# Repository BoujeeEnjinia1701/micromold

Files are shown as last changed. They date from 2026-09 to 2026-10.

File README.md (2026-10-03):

# MicroMold

     

**Area:** Advanced Manufacturing · **TRL:** 3 of 9 (proof of concept on paper) · **Value-engineering target:** USD 520 (estimated cost USD 590) · **Difficulty:** 3 of 5

A desktop injection molding press for recycled plastic: a lever or screw press with a heated barrel and interchangeable aluminum molds, turning shredded waste plastic into small useful parts.

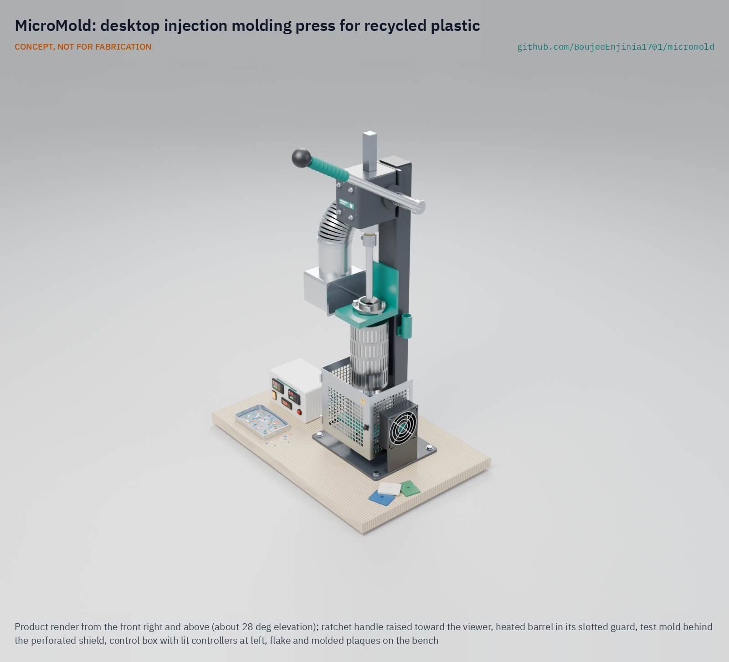
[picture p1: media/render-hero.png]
MicroMold: desktop injection molding press for recycled plastic, product render


[Exploded render](media/render-exploded.png) · [Interactive 3D model](media/viewer.html) · [Concept blueprint (PDF)](media/concept-blueprint.pdf) · [General arrangement (PDF)](cad/drawings/MMD-DWG-001.pdf) · [Sizing calculations](docs/04-calcs/01-sizing.md) · [Prototype build plan](docs/05-build-plan.md) · [Design decisions](docs/06-design-decisions.md) · [Review note](docs/REVIEW.md)

## Concept rationale

Molding turns sorted flake into finished parts, which sell for far more than flake sold by weight, and it lets a community make the small parts it would otherwise import. MicroMold uses the simplest injection process that still gives useful pressure: a heated barrel, a hand-driven plunger and a bolted aluminum mold. The drive is the rack and pinion of a 1 t arbor press on a taller column, turned by a ratchet handle, which gives a long stroke and 22.5:1 advantage from one bought tool (the brief allows a lever or screw drive; Amish chose this one on 2026-09-25).

It is open and garage-buildable because the value is in local making. Only the barrel and the molds need a lathe or mill, which most towns have in a machine shop, and a new mold costs tens of dollars in aluminum and machining rather than thousands for steel tooling. Open drawings let groups repair the press, share molds and adapt it, as the Precious Plastic community has done for its own machines.

## Burning platform

Only 9 % of the world's plastic waste is successfully recycled, while most is landfilled, incinerated or leaks into the environment ([OECD, 2022](https://www.oecd.org/en/about/news/press-releases/2022/02/plastic-pollution-is-growing-relentlessly-as-waste-management-and-recycling-fall-short.html); [*Global Plastics Outlook*](https://www.oecd.org/en/publications/global-plastics-outlook_de747aef-en.html)). Municipal solid waste reached 2.56 billion tonnes in 2022 and is projected to reach 3.86 billion tonnes by 2050, while collection covers only 31 % of waste in sub-Saharan Africa and 67 % in South Asia ([World Bank, *What a Waste 3.0*](https://www.worldbank.org/en/publication/what-a-waste)).

Recycling groups need products that pay for collection, and exporting scrap is getting harder: since 1 January 2021 the Basel Convention plastic waste amendments have required prior informed consent for most mixed or contaminated plastic waste shipments ([Basel Convention](https://www.basel.int/implementation/plasticwaste/amendments/overview/tabid/8426/default.aspx)). Adding value locally, by molding parts, is one of the few routes left for small operators.

## Where it could be used

### By industry

| Industry | Use |
| --- | --- |
| Community recycling and social enterprise | Turn sorted HDPE and PP flake into hooks, clips, knobs and tiles for local sale |
| Education and vocational training | Teach polymer processing, mold design and the circular economy with a press students can take apart |
| Repair and maintenance | Short runs of discontinued knobs, spacers, bushings and clips |
| Product design and prototyping | Low-cost aluminum bridge tooling to test a part in real thermoplastic before paying for steel molds |
| Agriculture and construction | Non-structural items such as cable clips, tile spacers, plant labels and hose guides (not food contact) |

### By country or region

| Country or region | Why it matters there |
| --- | --- |
| Kenya | Single-use plastic carrier and flat bags have been banned since 2017 ([NEMA](https://www.nema.go.ke/index.php?option=com_content&view=article&id=241)); durable recycled products are a natural outlet for collected HDPE and PP |
| Sub-Saharan Africa | Collection covers only 31 % of waste ([World Bank](https://www.worldbank.org/en/publication/what-a-waste)); products that pay for collection make it viable |
| South Asia (India, Bangladesh) | Collection reaches 67 % ([World Bank](https://www.worldbank.org/en/publication/what-a-waste)); as collection grows, sorted flake needs local outlets that add value |
| Brazil | The National Solid Waste Policy (Law 12,305 of 2010) directs public cleaning services to prioritize cooperatives of low-income waste pickers and allows federal support for their equipment ([Planalto, Lei 12.305/2010](https://www.planalto.gov.br/ccivil_03/_ato2007-2010/2010/lei/l12305.htm), arts. 36 and 42); a press is the kind of equipment that lets a cooperative sell parts rather than flake |
| United States | Plastics recycling was 8.7 % in 2018 ([US EPA](https://www.epa.gov/facts-and-figures-about-materials-waste-and-recycling/plastics-material-specific-data)); makerspaces and schools can use it for local recycling programs |
| Europe (Netherlands and wider EU) | Precious Plastic workspaces already run open lever presses ([Precious Plastic Academy](https://onearmy.github.io/academy/build/injection)); a bench press with higher pressure widens what they can mold |

## What sparked the idea

The starting point was the machine widely credited as the first injection molder. In 1872 the brothers John Wesley and Isaiah Smith Hyatt of Albany, New York, patented an apparatus in which a plunger pressed celluloid stock through a heated cylinder and out of a discharge nozzle, with a two-part mold held shut by a clamp to receive it ([US Patent 133,229, 1872](https://patents.google.com/patent/US133229A/en)). Every part of MicroMold is already in that patent: a plunger, a heated vertical barrel, a nozzle and a clamped split mold. Industry later moved to reciprocating screws and machines of many tonnes, but the plunger layout remains the simplest way to mold small parts, and it asks for no motor, gearbox or screw. The gap between that 150-year-old principle and the open lever press of Precious Plastic, which reaches about 45 bar from a floor-standing frame ([Precious Plastic Academy](https://onearmy.github.io/academy/build/injection)), is the space MicroMold aims at: a bench press with about twice the pressure for recycled flake.

## Problem

Community recycling produces shredded plastic with few local uses, and small-batch molding of parts is out of reach without an injection press. Only about 9 % of plastic waste is recycled worldwide, and groups that do collect and shred plastic often sell flake by weight for little return. Design with, not for: requirements must come from co-design sessions with recycling groups through a local partner.

## Concept

A bench-top, hand-operated plunger injection press. The rack-and-pinion head of a 1 t arbor press, on a taller steel column and turned by a ratchet handle through a torque-limiting socket, drives a 22 mm plunger down a vertical barrel heated by two 300 W band heaters and a 100 W nozzle heater, each zone under PID control. Melt fills a bolted two-plate aluminum mold held against a 4 mm nozzle by a screw lift table inside a perforated shield, where a small fan cools the mold; a load cell under the ram shows the injection force, and a side hood with a duct fan draws fumes from the funnel. The TRL 3 calculations give up to 34 g of HDPE per shot at 8.9 MPa (89 bar) with 250 N on the handle in about four ratchet pulls, a 12.3 min warm-up, about 11 parts per hour and 753 W from a single-phase socket. Value-engineering target: USD 520. Estimated cost of the constructable design: USD 590 (USD 70 over the target) for the press, and USD 684 with one mold; the press weighs about 39.8 kg against its 40 kg target (see the [sizing calculations](docs/04-calcs/01-sizing.md) and the [review note](docs/REVIEW.md)).

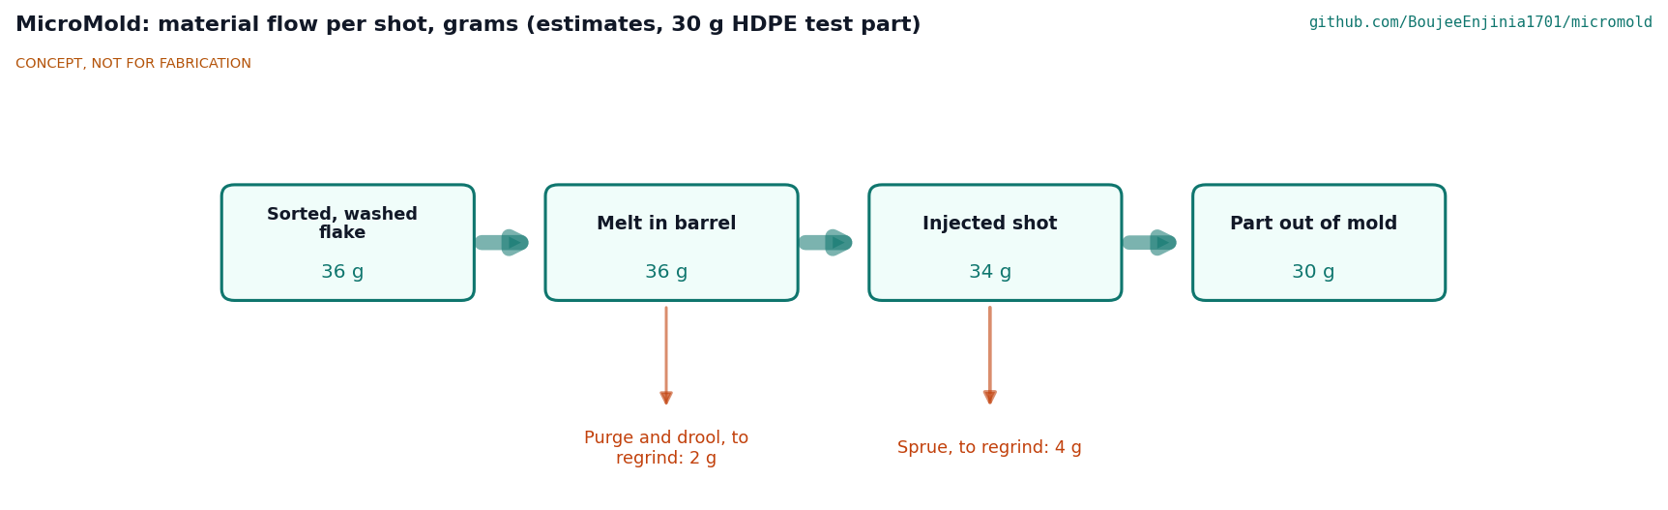
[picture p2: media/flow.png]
Material flow


Full design precis: [docs/02-concept.md](docs/02-concept.md)

## Key components

- Heated steel barrel (22 mm bore) with two 300 W band heaters, and a 4 mm nozzle with a 100 W heater
- Rack-and-pinion drive head from a 1 t arbor press on a steel column, with a 450 mm ratchet handle
- 22 mm plunger with a load cell, on a glass-epoxy thermal spacer, for force and pressure indication
- Two-plate aluminum mold set on a lift table raised by a handwheel nut on a Tr20 screw
- Insulation jacket and perforated guard; perforated nozzle zone shield
- Side fume hood with a 100 mm inline duct fan
- 120 mm mold cooling fan on the base plate
- Control box with two PID controllers, SSRs, fused inlet and independent thermal cut-out

The priced bill of materials is in [bom/bom.csv](bom/bom.csv); the parametric model is [cad/src/model.py](cad/src/model.py), with STEP and STL exports in `cad/step/` and `cad/stl/`.

## Building the prototype

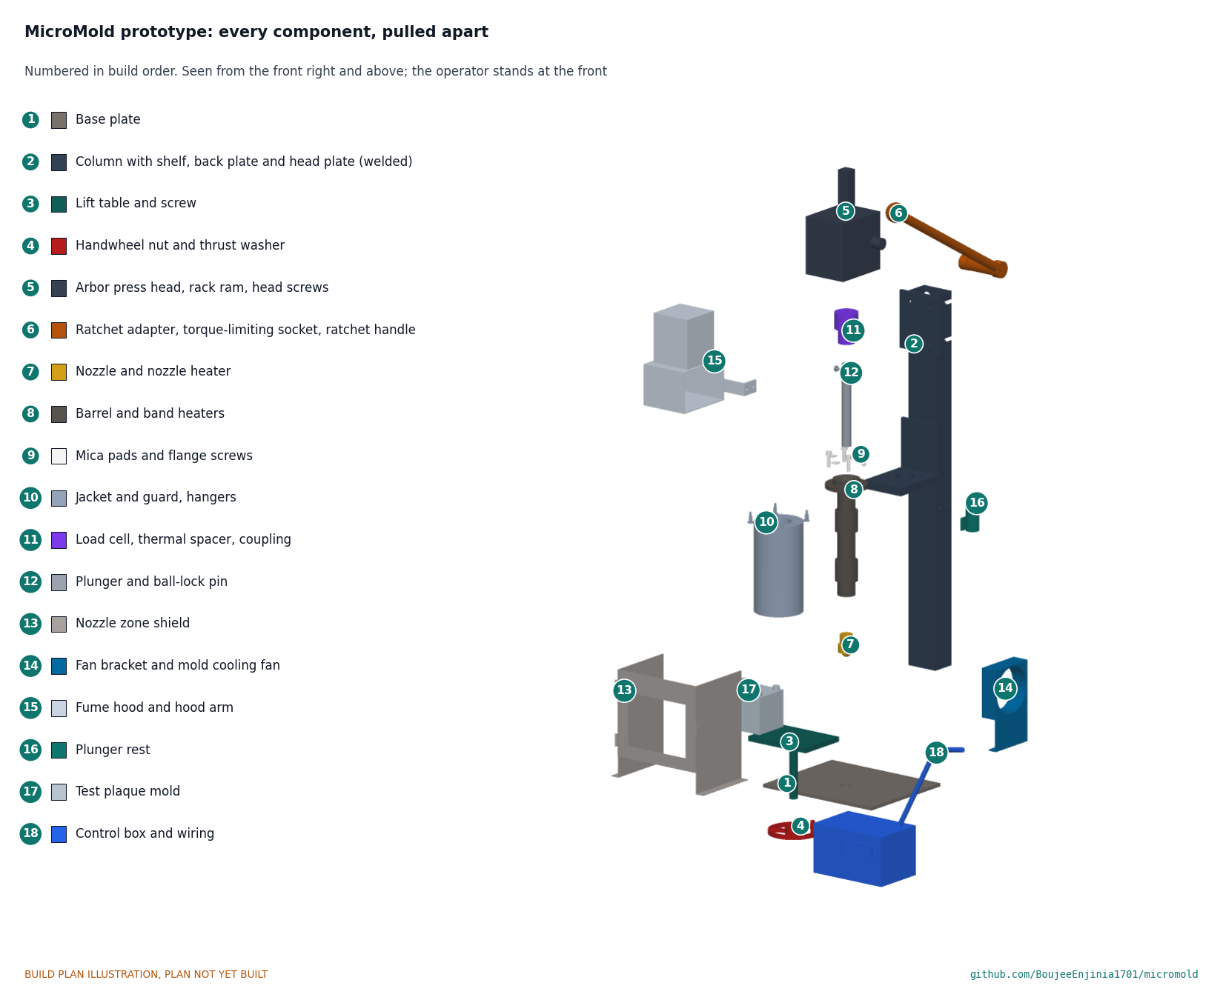
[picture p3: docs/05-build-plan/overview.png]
MicroMold prototype: every component pulled apart and numbered in build order


The [prototype build plan](docs/05-build-plan.md) (MMD-BLD-001) shows, in pictures, how to make each of the seventeen components and put them together in fourteen steps; nothing has been built yet. The frame is a steel column welded to a base plate with a shelf and a head plate, the barrel, nozzle and mold come from a local machine shop, the arbor press head is cut from its frame and bolted on, and the shield, fan bracket and hood are cut and folded from sheet. Writing the plan made the design buildable: the head and barrel fixings, the screw lift, the split jacket, the plunger coupling and the mold fastening were redesigned and fixings added (MMD-DDR-003, open for Amish's review). Every picture is drawn from the model, which checks that each part touches what it should, clears what it should not and can be put in place in the order given. Decisions still open are in the [design decisions register](docs/06-design-decisions.md).

## Safety

> **Safety:** Hot barrel, nozzle and molten plastic at up to 260 °C: use guards, heat-resistant gloves, long sleeves and eye protection, and keep faces off the injection axis. Close the nozzle zone shield before injecting. Process only HDPE, PP, LDPE and PS; never heat PVC or unknown plastics, and run the hood fan whenever the heaters are on, or work outdoors. Mains-voltage heaters: earth all metal parts, use a fused inlet and an RCD or GFCI supply, and have mains wiring done or checked by a qualified electrician to local electrical code. Keep hands clear of the rack, and release the ratchet pawl only with the handle in hand. See the safety section of the [design precis](docs/02-concept.md).

## Repository layout

| Folder | Contents |
| --- | --- |
| `docs/` | Problem, concept, requirements, calculations and design decisions |
| `cad/src/` | build123d Python source, the source of truth for all geometry |
| `cad/step/`, `cad/stl/` | Exported models for FreeCAD, other CAD tools and printing |
| `cad/drawings/` | 2D sketches and dimensioned drawings |
| `bom/` | Bill of materials |
| `electronics/` | KiCad schematics and PCB layouts |
| `firmware/` | Microcontroller code |
| `media/` | Renders, perspectives and photos |
| `build-log/` | Dated prototyping notes |

## Documentation

Controlled documents follow the portfolio [documentation standard](.kit/STANDARDS.md). Each carries a document ID (MMD-PRC-001 for the precis), a version and a revision history. Branded PDFs are built with `python .kit/render.py` and attached to GitHub Releases when a document is tagged, for example `MMD-PRC-001/v1.0`.

## Credits

Designed by Amish Chadha. See [CONTRIBUTORS.md](CONTRIBUTORS.md) for roles. To cite this design, use [CITATION.cff](CITATION.cff) (GitHub shows it as "Cite this repository").

AI assistance (Claude) was used to accelerate concept renders, prototype documentation and first-pass sizing calculations. Design direction and all decisions are Amish Chadha's, recorded in this repository's decision records (`docs/decisions/`).

## Licenses

- **Hardware** (CAD, drawings, BOM, electronics): [CERN-OHL-S v2](LICENSE)
- **Software** (firmware, scripts, notebooks): [MIT](LICENSE-SOFTWARE)

A project of the [Design Molecule](https://designmolecule.com) lab.

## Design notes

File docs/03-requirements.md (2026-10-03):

---
doc_id: MMD-REQ-001
title: MicroMold requirements
project: MicroMold
doc_type: Requirements
version: "0.8"
status: Draft
date: '2026-10-03'
author: Amish Chadha
license: CERN-OHL-S-2.0
revisions:
- version: "0.1"
  date: '2026-09-25'
  author: Amish Chadha
  change: Initial scaffold
- version: "0.2"
  date: '2026-09-25'
  author: Amish Chadha
  change: First measurable requirements for TRL 2, with status against first-order estimates
- version: "0.3"
  date: '2026-09-25'
  author: Amish Chadha
  change: TRL 3 status from MMD-CAL-001; R14 redefined to the press excluding molds and R13 to name the hood (MMD-DDR-001 D8, D9)
- version: "0.4"
  date: '2026-09-25'
  author: Amish Chadha
  change: Recommendations accepted by Amish (DDR-002)
- version: "0.5"
  date: '2026-09-26'
  author: Amish Chadha
  change: Budget approved by Amish
- version: "0.6"
  date: '2026-10-01'
  author: Amish Chadha
  change: Status from MMD-CAL-001 v0.4 for the constructable design (MMD-DDR-003); R14 measured against the value-engineering target
- version: "0.7"
  date: '2026-10-02'
  author: Amish Chadha
  change: Figures brought into line with MMD-CAL-001 v0.5 - R9 mass 39.8 kg, R14 press USD 590 (USD 70 over the target); no requirement status changed
- version: "0.8"
  date: '2026-10-03'
  author: Amish Chadha
  change: "R9 mass margin of 0.2 kg and the 180 N m socket setting accepted by Amish on 2026-10-03"
---

# MicroMold requirements

These are the requirements for the concept, checked by calculation at TRL 3 in MMD-CAL-001. Targets are proposals for review, not yet validated with users, and will be revised after co-design sessions (see MMD-PRB-001). "Met on paper" means met by calculation, and "met by design" means met by a stated feature; neither is demonstrated on hardware. Two targets changed in v0.3 under MMD-DDR-001: R14 covers the press without molds (D8), and R13 names the hood (D9). Three more changed in v0.4 under MMD-DDR-002, decided by Amish on 2026-09-25: R1 requires injection-grade flake, R9 allows 40 kg (was 35 kg) and R14 allows $500 (was $400). In v0.5 R14 allows $520, the budget Amish approved on 2026-09-26 to cover the priced BOM (MMD-DDR-002). In v0.6 that figure is read as a hypothetical value-engineering target, not a limit (Amish, 2026-10-01), and status is from MMD-CAL-001 v0.4, for the constructable design of MMD-DDR-003.

The **reference part** used throughout is a 30 g HDPE test plaque, 64 x 50 x 6 mm, molded from washed, dried flake of 3 to 8 mm.

Table 1. Requirements.

| ID | Requirement | Target | Status (MMD-CAL-001) | Verification (TRL 3 or later) |
| --- | --- | --- | --- | --- |
| R1 | Process the safe recycled thermoplastics | HDPE, PP, LDPE and PS flake of 3 to 8 mm from injection-molded items (caps, crates, buckets); bottle-grade HDPE and PVC excluded by procedure and labeling | Met by design (bottle grade would need about 24 MPa, CAL E6) | Design review; material trials later |
| R2 | Shot size | 30 g or more of HDPE per injection | **At risk:** 34.2 g ideal, about 25 g if the fresh charge is not tamped | Swept-volume calculation; later weighed shots |
| R3 | Injection pressure | 8 MPa (80 bar) or more at the melt with 250 N or less on the handle | Met on paper: 8.9 MPa at 0.60 drive efficiency (12.4 MPa at 0.84); fill needs about 4.8 MPa | Force and friction calculation; later load cell reading |
| R4 | Temperature control | Barrel and nozzle zones each settable from 150 to 260 °C, held within ±5 °C at the thermocouple; independent cut-out above 280 °C | Met by design, unverified | Controller and heater datasheets; later logging |
| R5 | Warm-up | Cold start to 220 °C in 15 min or less | Met on paper: 12.3 min with two 300 W bands | Heat capacity calculation; later timed start |
| R6 | Throughput | 8 or more reference parts per hour with one mold | Met on paper: 11.6 per hour with the mold cooling fan, mold about 47 °C (soak limited) | Cycle-time estimate; later timed trials |
| R7 | Mold envelope | Molds up to 150 x 120 mm footprint and 40 to 120 mm stack height; 40 cm² or more projected area at full pressure | Met on paper: 45 cm²; stacks of 30 to 120 mm fit | Clamp force calculation; model |
| R8 | Low-cost tooling | A two-plate aluminum mold for the reference part machinable on a manual mill or small CNC for $100 or less | Met on paper: $94 (indicative) | Quotation from a local shop |
| R9 | Bench size and mass | Press footprint 350 x 300 mm or less, top of handle 1.1 m or less above the bench, mass 40 kg or less without the control box | **At risk on mass:** 39.8 kg with an assumed 8 kg press head (0.2 kg margin accepted by Amish, 2026-10-03; 180 N m socket setting accepted the same day); 320 x 260 mm and 1,094 mm met | Model and mass estimate |
| R10 | Power supply | Single-phase 230 V or 120 V, 1 kW or less, 10 A or less at 120 V | Met on paper: 753 W, 6.3 A at 120 V | Heater and fan ratings |
| R11 | Touch-safe outer surfaces | Guard and jacket 60 °C or less at 220 °C set point and 25 °C ambient; nozzle and mold zone guarded | Met on paper: skin 48 °C; nozzle zone shield added | Thermal calculation |
| R12 | Electrical safety | Earthed frame, fused inlet, double-pole switch, RCD or GFCI supply, heaters and wiring rated for 250 °C at the barrel | Met by design, unverified | Design review against IEC 60204-1 principles |
| R13 | Fume control | A side hood with a duct fan at the funnel, and operation only under it or outdoors; set points above 260 °C blocked in the controller | Met on paper: about 124 m³/h | Hood calculation; design review |
| R14 | Affordable | Parts for the press, excluding molds (tooling, see R8), at or under the $520 value-engineering target (a hypothetical control target) | **Over the value-engineering target: $590, USD 70 over** ($684 with one mold) | Priced BOM (`bom/bom.csv`) |
| R15 | Garage-buildable | Everything except the barrel and the mold built with hand tools, a drill press and optional welding | Met by design: the barrel with its nozzle and the molds come from a local machine shop; the plunger is only cross-drilled | Build sequence review |
| R16 | Repeatable parts | Part mass within ±3 % over 10 consecutive shots | Not verifiable at TRL 3 | Later bench trials (TRL 4, not in the current phase) |

## Assumptions

- HDPE melt density about 0.75 g/cm³ at 200 to 220 °C; solid density about 0.95 g/cm³ (typical handbook values, estimates). The other property values are in MMD-CAL-001, Table 1.
- Arbor press drive: pinion pitch radius about 20 mm, 450 mm ratchet handle, design efficiency 0.60 (0.84 calculated), to be checked on the chosen press.
- Processing temperatures follow published melt ranges: HDPE 190 to 230 °C, PP 200 to 240 °C, LDPE 220 to 245 °C, PS 180 to 260 °C ([RJC Mold](https://rjcmold.com/guides/plastic-melting-point-chart)).
- Four M10 class 8.8 cap screws in thread inserts, preloaded to about 20 kN each, clamp the mold plates, with a factor of 2 against melt pressure opening the parting plane.

## Requirements not met or at risk

- **R14 cost:** value-engineering target: USD 520. Estimated cost of the constructable design: USD 590 (USD 70 over the target) for the press, with molds counted as tooling; USD 684 with the first mold. The parts added to make the design buildable account for USD 37 (MMD-DDR-003) and the plunger rest and torque-limiting socket for USD 46 (decisions of 2026-10-02); cost drivers and savings are in MMD-DEC-001.
- **R9 mass:** 39.8 kg against 40 kg, with an assumed 8 kg arbor press head; the margin depends on the real press.
- **R2 shot size:** met only if each top-up of flake is tamped with the press while loading.
- **R16** cannot be assessed until hardware exists (TRL 4, on hold).

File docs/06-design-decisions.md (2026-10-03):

---
doc_id: MMD-DEC-001
title: MicroMold design decisions register
project: MicroMold
doc_type: Design decisions register
version: "0.4"
status: Draft
date: '2026-10-03'
author: Amish Chadha
license: CERN-OHL-S-2.0
revisions:
  - version: "0.1"
    date: '2026-10-01'
    author: Amish Chadha
    change: Register opened with the build plan; budget treated as a value-engineering target
  - version: "0.2"
    date: '2026-10-02'
    author: Amish Chadha
    change: Amish approved the recommendations for open items 1 to 7 on 2026-10-02 (MMD-DDR-003 accepted with P1 confirmed against the bought press, lift-out loading with a plunger rest, bench hole, torque-limiting socket, Precious Plastic workspace near Irving as first candidate, first product mold, appearance model); moved to decisions made
  - version: "0.3"
    date: '2026-10-02'
    author: Amish Chadha
    change: Value engineering updated for the torque-limiting socket and plunger rest (press USD 590, USD 70 over the target)
  - version: "0.4"
    date: '2026-10-03'
    author: Amish Chadha
    change: "Amish accepted the 180 N m socket setting and the 0.2 kg R9 mass margin on 2026-10-03; row added to decisions made"
---

# MicroMold design decisions register

Every design decision still to be made, and every decision made, in one place. Each decision is argued in full in its decision record under `docs/decisions/`; this register is the index Amish works from. The build plan (`docs/05-build-plan.md`) describes the design as it stands and does not list open decisions.

## Open decisions

None. All open decisions were decided on 2026-10-02.

## To confirm when parts are bought

| # | What to confirm | Why it matters | Source |
| --- | --- | --- | --- |
| 1 | The arbor press: a 28 mm ram 255 mm or longer with 150 mm of engaged travel; a head that can be cut from its frame with a flat back face and enough metal for four M10 holes 20 deep; the head's mass (8 kg assumed) | Sets the stroke, the head fixing and R9's mass margin (1.0 kg) | MMD-DDR-003, P1; MMD-CAL-001 [K1] |
| 2 | The press's lever hub: its outside diameter and bore, to take the welded square drive | The ratchet adapter is made from it | MMD-DDR-003, P13 |
| 3 | The load cell is about 56 mm across, has a top M12 stud and a base flange with three M5 through holes (46 mm circle assumed) | The spacer's tapped holes are drilled to match it | MMD-DDR-003, P6 |
| 4 | The handwheel's hub takes a Tr20 x 4 nut (about 36 mm across) | The handwheel nut is made from it | MMD-DDR-003, P7 |
| 5 | The mold cooling fan's corner holes are on a 105 mm square | The fan bracket's holes | MMD-DDR-003, P10 |
| 6 | The nozzle heater band fits a 24 mm body and is no more than 18 mm wide | The nozzle body length | MMD-DDR-003, P4 |
| 7 | The bench top's thickness and the clear space under it (60 mm or more below the hole) | The lift screw drops through it | MMD-DDR-003, P7 |

## Value engineering

Value-engineering target: USD 520 (a hypothetical control target, not a limit). Estimated cost of the constructable design: USD 590 (USD 70 over the target) for the press; USD 684 with the test mold, which is tooling outside the target (USD 94, R8). Main cost drivers and savings worth trying:

- The largest lines are the arbor press head with column tube and ratchet (USD 110), the control box (USD 55), the fume hood and duct fan (USD 48), the barrel (USD 45), the load cell and display (USD 35) and the lift table, screw and handwheel (USD 30).
- Making the design constructable added USD 37: the construction parts of line 19 (USD 30: head mounting plate and screws, plunger coupling and ball-lock pin, ratchet adapter, hood arm and rivnuts), the bracket's back plate and cap screws (USD 4) and the shield's hinges and latch (USD 3). The mold rose USD 4 for screws, inserts and dowels.
- The decisions of 2026-10-02 added USD 46: the torque-limiting socket (line 21, USD 40, an estimate at the midpoint of a USD 30 to 50 retail band) and the plunger rest (line 20, USD 6, an estimate by parts).
- Savings worth trying: a used arbor press (often under half the new price); counting the duct fan and duct (USD 48) as workshop extraction shared with other machines, as the molds are counted as tooling, which would bring the press to USD 542 (that removes cost from scope rather than saving it, so it does not compare like with like with the target); buying the two PID controllers and relays as a pre-wired dual-zone controller; and a ball-lock pin replaced by a plain clevis pin and R-clip (about USD 4 less).

## Decisions made

| Date | Decision | Decided by | Record |
| --- | --- | --- | --- |
| 2026-09-25 | TRL 2 review items D1 to D10: rack-and-pinion drive from a 1 t arbor press on a taller column, vertical barrel with the mold below, plunger injection, two PID zones, bolted two-plate molds on a screw lift table, 10 kN load cell, test plaque first, molds as tooling, side hood with duct fan, a partner that already shreds HDPE or PP | Amish: "i accept all your recommendations, go with them across all repos." | MMD-DDR-001, MMD-DDR-002 |
| 2026-09-25 | N1 to N5: budget USD 500 for the press, 40 kg mass target, two 300 W barrel bands, a mold cooling fan, injection-grade flake only | Amish, same instruction | MMD-DDR-002 |
| 2026-09-26 | Budget USD 520 to cover the priced BOM (O3, option (a)) | Amish: "i approve all the budget items." | MMD-DDR-002 v0.2 |
| 2026-09-30 | Make the design physically buildable as the build plan is drawn; changes recorded as draft for review | Amish: "If you are realising that the design cannot be built as per concept - fix the design assumptions to match and be physically feasible as you draw the illustrations." | MMD-DDR-003 (its changes were accepted on 2026-10-02, below) |
| 2026-09-30 | Outstanding decisions are kept in this register, not in the build plan | Amish: "don't log outstanding decisions in this build plan - that is not the place for it." | This register |
| 2026-10-01 | `budget_usd` is a hypothetical value-engineering target, not a spending limit | Amish: "the budgets are a hypothethical control target to ensure we are thinking along a value engineering lens." | This register; MMD-REQ-001 R14 |
| 2026-10-02 | Design for construction accepted: the changes P1 to P15, with one condition: P1 (cutting the head from the arbor press casting and tapping four M10 holes in its back) is confirmed against the bought press before it is cut | Amish: "i approve your recommendations for all 555 open decisions." | MMD-DDR-003, Table 1 |
| 2026-10-02 | Loading: option (a), pull the ball-lock pin and lift the plunger out to load, then refit it to tamp and inject; a simple plunger rest is added on the column so the hot plunger is never laid on the bench | Amish: "i approve your recommendations for all 555 open decisions." | MMD-DDR-003, A1 |
| 2026-10-02 | Lift screw: option (a), a 25 mm hole through the bench for the lift screw is accepted | Amish: "i approve your recommendations for all 555 open decisions." | MMD-DDR-003, A2 |
| 2026-10-02 | Overload protection: option (b), a torque-limiting socket on the ratchet adapter, set so the ram cannot exceed the press rating, and checked against the load cell at TRL 4 | Amish: "i approve your recommendations for all 555 open decisions." | MMD-DDR-003, A3; `docs/REVIEW.md`, TRL 3 safety concerns |
| 2026-10-02 | First co-design partner: a community plastic recycling workspace that already shreds HDPE or PP; first candidate to approach a Precious Plastic workspace near Irving, Texas | Amish: "i approve your recommendations for all 555 open decisions." | MMD-DDR-001, O1 |
| 2026-10-02 | First product mold after the test plaque: a flat, single-cavity part of 25 g or less that fits the 120 x 90 mm mold plates, such as a coaster, tile or cable clip, chosen with the partner from what it can sell | Amish: "i approve your recommendations for all 555 open decisions." | MMD-DDR-001, O2 |
| 2026-10-02 | Appearance model: accept differences 1, 3, 5 and 6; update 2 and 4 to the constructable design (no guide rods; cap screws into inserts, no nuts), and add the screw lift, flange and fan bracket at the same time | Amish: "i approve your recommendations for all 555 open decisions." | `docs/REVIEW.md`, 2026-09-26, items 1 to 6 |
| 2026-10-03 | The 180 N m setting of the torque-limiting socket and the R9 mass margin of 0.2 kg (39.8 kg against 40 kg) accepted | Amish: "TIght Margins - i accept the margins" | MMD-REQ-001, R9; MMD-CAL-001; [REVIEW.md](REVIEW.md), session 2026-10-03 |

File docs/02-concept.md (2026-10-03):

---
doc_id: MMD-PRC-001
title: MicroMold design precis
project: MicroMold
doc_type: Design precis
version: "0.8"
status: Draft
date: '2026-10-02'
author: Amish Chadha
license: CERN-OHL-S-2.0
revisions:
- version: "0.1"
  date: '2026-09-25'
  author: Amish Chadha
  change: Initial scaffold
- version: "0.2"
  date: '2026-09-25'
  author: Amish Chadha
  change: Populate to TRL 2 (architecture, components, first-order numbers, design choices, safety, open questions, media)
- version: "0.3"
  date: '2026-09-25'
  author: Amish Chadha
  change: TRL 3 update from MMD-CAL-001 and MMD-DDR-001 (ratchet handle, 4 mm nozzle, load cell spacer, 20 mm bracket, nozzle zone shield, side fume hood, raised nozzle; numbers and design choices updated)
- version: "0.4"
  date: '2026-09-25'
  author: Amish Chadha
  change: Recommendations accepted by Amish (DDR-002)
- version: "0.5"
  date: '2026-09-26'
  author: Amish Chadha
  change: Budget approved by Amish ($520)
- version: "0.6"
  date: '2026-10-01'
  author: Amish Chadha
  change: Constructable design (MMD-DDR-003) and build plan (MMD-BLD-001); budget read as a value-engineering target
- version: "0.7"
  date: '2026-10-02'
  author: Amish Chadha
  change: 'Decisions of 2026-10-02 (MMD-DEC-001 v0.2): lift-out loading with a plunger rest, torque-limiting socket against overload, first product mold, first candidate partner'
- version: "0.8"
  date: '2026-10-02'
  author: Amish Chadha
  change: Figures brought into line with MMD-CAL-001 v0.5 - torque-limiting socket and plunger rest in Table 1 (items 19 to 21), overload 8.3 kN with the socket, mass 39.8 kg, press USD 590
---

# MicroMold design precis

## Summary

MicroMold is a bench-top, hand-operated plunger injection press for recycled HDPE, PP, LDPE and PS. The rack-and-pinion head of a 1 t arbor press, mounted on a taller steel column and turned by a 450 mm ratchet handle through a torque-limiting socket set to 180 N m, drives a 22 mm plunger down a vertical steel barrel heated by two 300 W band heaters. Melt leaves a heated 4 mm nozzle into a two-plate aluminum mold that a screw lift table holds against the nozzle, inside a perforated nozzle zone shield, where a small fan cools the mold, and a side hood with a duct fan draws fumes from the funnel. The TRL 3 calculations (MMD-CAL-001 v0.5) give a shot of up to 34.2 g at 8.9 MPa (89 bar) with 250 N on the handle, delivered in about four ratchet pulls; a warm-up of 12.3 min; and about 11.6 parts per hour from 753 W of single-phase power. Value-engineering target: USD 520. Estimated cost of the constructable design: USD 590 (USD 70 over the target) for the press, and USD 684 with one mold, which is tooling. It weighs about 39.8 kg against a 40 kg target. All figures are estimates. The design was made buildable on 2026-10-01 (MMD-DDR-003) and the prototype build plan is MMD-BLD-001 (`docs/05-build-plan.md`).

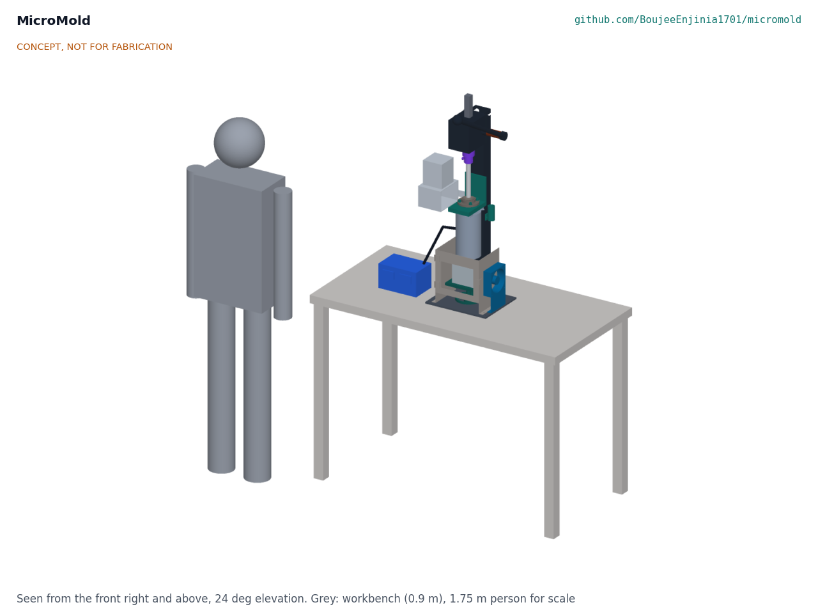
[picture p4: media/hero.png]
MicroMold on a workbench


*Figure 1. MicroMold on a 0.9 m workbench with a 1.75 m person for scale. Plunger raised for loading; test mold seated on the nozzle inside the shield. Generated from the parametric model `cad/src/model.py`.*

## How it works

1. **Heat.** Two PID controllers drive the barrel zone (two 300 W band heaters) and the nozzle zone (a 100 W band heater) to the set point for the resin, for example 210 °C for HDPE. An insulation jacket and a perforated guard keep the outer surface near 48 °C. The duct fan runs whenever the heaters are on. Feedstock is flake from injection-molded items such as caps, crates and buckets; bottle-grade HDPE is too stiff for a hand press.
2. **Load.** The operator pulls the ball-lock pin, lifts the plunger out and sets it on a plunger rest on the column, never on the bench (decided by Amish, 2026-10-02), pours washed, dried flake into the funnel, refits the plunger and tamps each of two or three top-ups down with the press itself, because loose flake has about a third to a half of the density of melt and an untamped charge wastes stroke (MMD-CAL-001, A4).
3. **Soak.** The fresh charge melts above the melt left from the last shot. The barrel holds 2.2 shots, so each charge soaks for about two cycles, about 12 min, against the 9.3 min a 22 mm column of tamped flake needs.
4. **Clamp.** The operator bolts the two mold plates together, sets the mold on the lift table, closes the shield's front and turns the handwheel nut, reached under the front, until the nozzle seats in the mold's spherical seat.
5. **Inject and hold.** The operator fills the mold in about four pulls of the ratchet handle, each moving the plunger about 31 mm, over about 10 s; the pawl holds the ram between pulls. The operator then holds pressure for about 30 s while the gate freezes. A load cell above the plunger shows its force, so the melt pressure (force divided by 380 mm² of plunger area) can be read and logged.
6. **Cool and eject.** With the mold cooling fan running, the plaque cools in the mold for about 1 min, then the mold is lowered, unbolted and opened. Sprue and purge go back to the regrind bin.

Material flow per shot

*Figure 2. Material flow per shot for the 30 g reference part. All values are estimates: about 2 g of purge and drool and 4 g of sprue return to regrind.*

## Main components

Table 1. Main components. Numbers match `bom/bom.csv` and Figure 4.

| # | Component | Choice | Notes |
| --- | --- | --- | --- |
| 1 | Base plate | 320 x 260 x 8 mm steel, bolted to the bench | Carries the column and the mold clamp; 8 mm from MMD-DDR-003 |
| 2 | Column and drive head | Rack-and-pinion head of a 1 t arbor press on an 80 x 60 x 3 mm steel tube column 0.9 m tall; 450 mm, 1/2 in drive ratchet handle on the pinion shaft | Ratchet added at TRL 3: one pull moves the plunger only about 31 mm |
| 3 | Rack ram | From the arbor press, 28 mm square, 255 mm or longer | 150 mm of travel with the rack still engaged; to confirm on the chosen press |
| 4 | Plunger load cell | 10 kN compression cell with HX711 amplifier and display, on a 10 mm G-11 glass-epoxy spacer | The spacer keeps the cell near 27 °C instead of about 94 °C |
| 5 | Plunger | 22 mm ground steel rod, 200 mm, cross-drilled for a pinned floating coupling | 0.05 to 0.10 mm diametral clearance (22 H8/f7); no seal |
| 6 | Heated barrel | 42 mm steel bar bored and honed to 22 mm, 260 mm long, 80 mm flange and loading funnel | Machine shop part |
| 7 | Band heaters | Two 300 W mica band heaters, 42 mm ID x 50 mm | Barrel zone, one PID loop; 4.5 W/cm²; 300 W from MMD-DDR-002 |
| 8 | Nozzle and nozzle heater | Steel nozzle with a 4 mm orifice, radiused tip; 100 W band heater; tip at 190 mm above the bench | Second PID loop; orifice enlarged from 3 mm at TRL 3 |
| 9 | Barrel shelf and heat break | 20 mm steel shelf and 8 mm back plate welded to the column; the 100 mm flange sits on four mica pads, held by four M8 cap screws | Carries the plunger reaction into the column; back plate from MMD-DDR-003 |
| 10 | Insulation jacket and guard | 25 mm mineral wool in an aluminum skin, perforated steel guard | Skin about 48 °C |
| 11 | Mold clamp | 170 x 126 mm lift table on a Tr20 x 4 screw, raised by a handwheel nut on the base plate; the screw drops through a hole in the bench | Table top 60 to 160 mm: stacks of 30 to 120 mm; screw lift from MMD-DDR-003 |
| 12 | Aluminum mold set | Two 6061 plates, 120 x 90 x 45 mm each, four M10 x 70 cap screws in thread inserts, two dowels, sprue tapering 5 to 7 mm | First mold: test plaque; tooling outside the press budget |
| 13 | Control box | Two PID controllers with set point limit, two 25 A SSRs on a heat sink, fused IEC inlet, double-pole switch, independent thermal cut-out, fan outlet, force display | Mains enclosure; earthed |
| 14 | Heater and sensor wiring | High-temperature wire in glass-fiber sleeving, two K-type thermocouples | 250 °C rated at the barrel |
| 16 | Nozzle zone shield | Perforated steel sides and hinged front around the nozzle and mold | Added at TRL 3 for R11 and melt spit |
| 17 | Fume hood and duct fan | Side hood, 150 x 100 mm face, 100 mm from the funnel axis; 100 mm inline fan; 3 m of duct | Added at TRL 3 (MMD-DDR-001 D9); about 124 m³/h |
| 18 | Mold cooling fan | 120 mm mains axial fan, about 18 W, on an angle bracket on the base plate, blowing on the mold through the shield side | Added by MMD-DDR-002; mold about 47 °C instead of about 92 °C |
| 19 | Construction parts | Head mounting plate, plunger coupling and ball-lock pin, ratchet adapter, hood arm | Added to make the design buildable (MMD-DDR-003) |
| 20 | Plunger rest | A cup on a plate on two M6 rivnuts in the column's right wall, 400 mm above the bench | Holds the plunger upright, tip down, while the barrel is loaded; the hot plunger is never laid on the bench (decision of 2026-10-02) |
| 21 | Torque-limiting socket | 1/2 in drive, set to 180 N m, between the ratchet adapter and the ratchet | Slips at about a 400 N pull so the ram cannot exceed the press rating; checked against the load cell at TRL 4 (decision of 2026-10-02) |

Item 15 (hardware and consumables) is in the BOM but not modeled. The general arrangement is drawing MMD-DWG-001 (`cad/drawings/`).

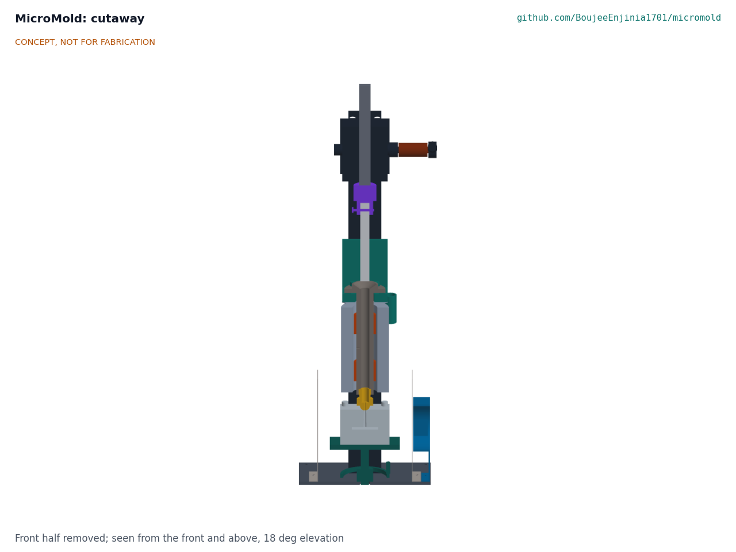
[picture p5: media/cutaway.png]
Cutaway


*Figure 3. Section on the injection axis: drive head and ram at the top, load cell and spacer (purple), plunger raised above the funnel, barrel with the two band heaters inside the jacket and guard, bracket (teal), nozzle (gold) seated on the mold with its sprue and plaque cavity, lift table and screw jack on the base plate, and the sides of the nozzle zone shield.*

## Numbers from MMD-CAL-001

All values are first-principles estimates. Assumptions are in MMD-CAL-001, Table 1; the tags point to the lines of `docs/04-calcs/sizing.py` that print them.

Table 2. Key numbers.

| Quantity | Value | Requirement |
| --- | --- | --- |
| Swept volume and shot | 45.6 cm³, 34.2 g HDPE ideal; about 25 g if the fresh charge is not tamped [A1, A2, A4] | R2 at risk |
| Drive ratio and efficiency | 22.5:1; 0.60 design, 0.84 calculated [B1] | |
| Plunger force and melt pressure at 250 N | 3.38 kN and 8.9 MPa (89 bar, 1,288 psi) at 0.60; 12.4 MPa at 0.84 [B2] | R3 met on paper, 11 % margin |
| Stroke per ratchet pull | 31.4 mm per 90° pull; 3.8 pulls per shot [B5] | |
| Overload (700 N on the handle) | 13.2 kN, 34.7 MPa, 1.35 times the press rating without a limiter; with the torque-limiting socket at 180 N m (198 N m worst case) 8.3 kN, 21.8 MPa, 0.85 times the rating [B4, B4a, B4b] | Parts sized for the limited case |
| Fill pressure, 4 mm nozzle, 10 s fill | About 4.8 MPa [E3] | |
| Mold clamp limit | 45 cm² projected area at 8.9 MPa [D2] | R7 met on paper |
| Warm-up to 220 °C | 12.3 min barrel zone with 2 x 300 W, 6.6 min nozzle [G4] | R5 met on paper |
| Standing losses at 220 °C | 103 W; jacket skin 48 °C [G2, G3] | R11 met on paper |
| Melt soak for a 22 mm column | 9.3 min for tamped flake [H1] | |
| Cycle | 5.2 min, 11.6 parts per hour with the mold fan (soak limited); mold about 47 °C [H3, H6] | R6 met on paper |
| Electrical load | 753 W; 3.3 A at 230 V, 6.3 A at 120 V [I1] | R10 met on paper |
| Energy per shot | About 20 Wh, 0.66 kWh per kg of parts [I2] | |
| Fume hood flow | About 124 m³/h [J1] | R13 met on paper |
| Mass | 39.8 kg without the control box, against 40 kg [K1] | R9 at risk |
| Size | 320 x 260 mm base; handle 1,094 mm above the bench at the start of a pull [K2] | R9 met on size |
| Parts cost | $590 press, against a $520 value-engineering target; $684 with one mold [L1, L2] | R14 USD 70 over the value-engineering target |

## Key design choices

These follow MMD-DDR-001 and MMD-DDR-002. Each was decided by Amish, 2026-09-25: go with recommendation.

- **Drive: rack and pinion from an arbor press (D1).** The rack, pinion and head of a 1 t arbor press on a taller column give 22.5:1 from one bought part. A screw press stays as a variant for small, thick parts. At TRL 3 the fixed handle is replaced by a ratchet handle, because a shot needs 344° of pinion rotation.
- **Vertical barrel, mold below (D2).** Gravity keeps the melt at the nozzle and the operator loads from the top. The mold is changed at bench height.
- **Plunger, not screw (D3).** A reciprocating screw would mix and melt better but needs a motor, gearbox and a much more complex barrel.
- **Two heat zones (D4).** A separate nozzle zone stops the nozzle freezing between shots at the cost of a second PID and SSR.
- **Bolted two-plate aluminum molds on a lift table (D5).** Bolts are slow but cheap and hold 45 cm² at full pressure. A toggle clamp frame (about $40) is a later upgrade. The nozzle tip is now 190 mm above the bench so that 120 mm stacks fit.
- **Load cell for pressure indication (D6).** A number for each shot helps a group learn and record settings. A glass-epoxy spacer keeps the cell cool.
- **First mold: a test plaque (D7).** A 64 x 50 x 6 mm plaque shows fill, shrinkage and surface quality and can be cut into test bars. The first product mold is a flat, single-cavity part of 25 g or less that fits the 120 x 90 mm plates, such as a coaster, tile or cable clip, chosen with the partner from what it can sell (decided by Amish, 2026-10-02).
- **Budget (D8, DDR-002).** The budget covers the press and is $520, approved by Amish on 2026-09-26 to cover the priced BOM; molds are tooling, reported separately (R8). On 2026-10-01 Amish set out that the budget is a hypothetical value-engineering target, not a limit. The constructable press is estimated at $544, $24 over the target (MMD-DDR-003).
- **Fume control (D9).** A side hood with a duct fan at the funnel, plus a written condition to run only under it or outdoors.
- **Heaters, mold cooling, mass and feedstock (DDR-002).** Two 300 W barrel bands for a 12.3 min warm-up; a 120 mm fan at the mold so parts eject from a mold near 47 °C; a 40 kg mass target for a bench-bolted press; and injection-grade flake only.
- **Co-design partner type (D10).** The first partner is to be a group that already shreds HDPE or PP; the first candidate to approach is a Precious Plastic workspace near Irving, Texas (decided by Amish, 2026-10-02).

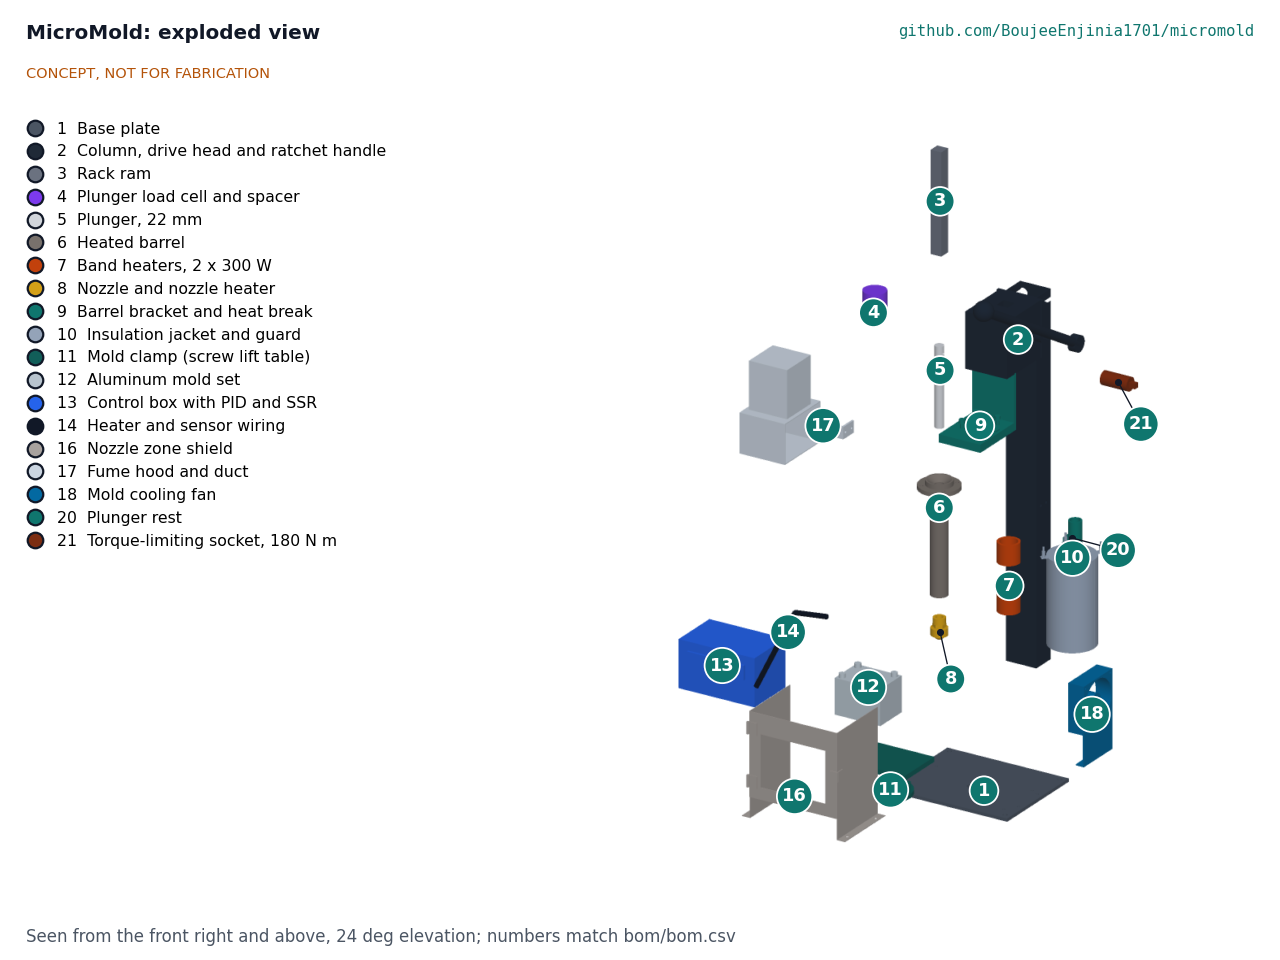
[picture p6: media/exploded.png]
Exploded view


*Figure 4. Exploded view with BOM numbers.*

## Safety

> **Safety:** MicroMold combines mains voltage, surfaces and molten plastic at up to 260 °C, stored pressure in the melt, a long ratchet lever and plastic fumes. It is a concept for a supervised workshop, not a consumer appliance.

- **Hot plunger.** The plunger's top end reaches about 94 °C. Lift it out for loading only in heat-resistant gloves and set it on the plunger rest on the column, never on the bench.
- **Hot surfaces and melt.** The barrel, nozzle, mold and purge reach 180 to 260 °C, and molten plastic sticks to skin. The funnel top is a working surface at about 150 °C. Keep the jacket guard and the nozzle zone shield in place, wear heat-resistant gloves, long sleeves and eye protection, and never look down the barrel.
- **Pressure.** Trapped melt can spit from the nozzle or the parting line. Without a limiter, an operator hanging body weight on the handle could reach about 35 MPa, which would open the parting line of the test mold (MMD-CAL-001, D3); with the socket the most is about 22 MPa. Close the shield before injecting and keep faces away from the axis. A torque-limiting socket on the ratchet adapter, set so the ram cannot exceed the press rating, limits the force whoever pulls (decided by Amish, 2026-10-02); it is checked against the load cell at TRL 4.
- **Fumes.** Process only HDPE, PP, LDPE and PS within their published ranges. Never heat PVC, which releases hydrogen chloride, or unknown and mixed plastics ([Precious Plastic Academy](https://onearmy.github.io/academy/plastic/basics)). Overheated PS can release styrene. Run the hood fan whenever the heaters are on, or work outdoors. Set point limits of 260 °C are set in both controllers.
- **Mains electricity.** Heaters run at mains voltage next to steel parts. Earth the frame and every metal part, use a fused inlet, double-pole switch and an RCD (30 mA) or GFCI supply, rate wiring at the barrel for 250 °C, and fit an independent thermal cut-out. Mains wiring must be done or checked by a qualified electrician to local electrical code.
- **Moving parts and lever.** The ratchet holds the ram under load: release the pawl only with the handle in hand. The ram and pinion can pinch; keep hands clear of the rack. The mold cooling fan runs at mains voltage: keep its finger guard fitted and its lead clear of the hot barrel and nozzle.
- **Fire.** Unattended heaters are a fire risk. Switch off at the inlet after use; keep flake and rags away from the barrel.
- **Product use.** Recycled parts of unknown history are not suitable for food contact, toys for young children, medical or safety-critical uses.

## Open questions after TRL 3

- Ram length and travel of real 1 t arbor presses: is a 255 mm ram with 150 mm of engaged travel available, and how heavy is the head? This sets R9, now at 39.8 kg against 40 kg.
- How dense is a tamped, part-melted charge at injection time? This sets R2.
- Is the fan enough to keep the mold near 47 °C in practice, and how dense is the charge after the shorter soak-limited cycle? This sets R6.
- Nozzle temperature for each resin, and mold design rules for the group's own machinists: draft, venting, gate size and ejection.
- Which first products would sell locally? The first product mold is a flat part of 25 g or less, such as a coaster, tile or cable clip (decided 2026-10-02); which one is chosen with the co-design partner.

Concept media: [blueprint sheet](../media/concept-blueprint.pdf), [interactive 3D model](../media/viewer.html). General arrangement: [MMD-DWG-001](../cad/drawings/MMD-DWG-001.pdf).

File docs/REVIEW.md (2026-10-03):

# Review note: MicroMold

## Session 2026-09-25: /populate to a strong TRL 2

### What was done

- `docs/01-problem.md` (MMD-PRB-001 v0.2): the problem in numbers with sources, users and context, constraints, out of scope, prior work (Precious Plastic injection machine, processing data, portfolio links); co-design checklist kept, with questions for users.
- `docs/03-requirements.md` (MMD-REQ-001 v0.2): 16 measurable requirements (R1 to R16) with targets, status against first-order estimates and planned verification; assumptions; requirements not met.
- `docs/02-concept.md` (MMD-PRC-001 v0.2): how it works, components table numbered to the BOM, first-order numbers with assumptions, design choices with options, safety section, open questions.
- `cad/src/concept_media.py`: massing model of 14 parts (base plate, column and drive head, rack ram, load cell, plunger, barrel, band heaters, nozzle, bracket, jacket and guard, mold clamp, mold set, control box, wiring), shown on a 0.9 m workbench with a 1.75 m person for scale.
- `media/`: hero, blueprint sheet (PNG, PDF, SVG), cutaway, exploded view with BOM callouts, material flow per shot (estimates marked), `model.glb` and `viewer.html`.
- `bom/bom.csv`: 15 lines with indicative prices, numbered to match the exploded view; `bom/bom-notes.md` updated.
- `README.md`: hero image and links line; concept rationale, burning platform, industry and region tables and the idea's trigger expanded with sources; problem, concept, key components and safety updated.
- `docs/pdf/`: branded PDFs of the three controlled documents.
- `project.yaml`: unchanged. The pitch says "a lever or screw press"; the proposed rack-and-pinion drive is a lever-driven press, so the pitch still holds.

### Key results (estimates, to be checked at TRL 3)

| Quantity | Estimate | Requirement |
| --- | --- | --- |
| Shot size | about 34 g HDPE (46 cm³ swept) | R2 met |
| Melt pressure at 250 N on the handle | about 8.9 MPa (89 bar) | R3 met, about 10 % margin |
| Mold clamp limit | about 45 cm² projected area | R7 met |
| Warm-up to 220 °C | about 10 to 12 min | R5 met |
| Cycle | about 6 min, 10 parts per hour | R6 met on paper; melt soak unverified |
| Power | about 600 W; 2.6 A at 230 V | R10 met |
| Energy | about 14 Wh per shot, about 0.5 kWh per kg of parts | |
| Mass and size | about 32 kg; 320 x 260 mm base; about 1.06 m to the handle | R9 met |
| Parts cost | about $399 press; about $489 with one mold | R14 **not met** |

Requirements not met or at risk:

- **R14 cost:** about $489 with one mold against the $400 budget (press alone about $399, no margin).
- **R13 fume control:** no extraction in the concept or BOM.
- **R15 garage-buildable:** partly met; the barrel needs a lathe and the mold a mill.
- **R11:** met on paper for the jacket, but the nozzle and mold zone guard is not yet designed.
- **R3** and **R6** are at risk: R3 depends on the assumed 60 % drive efficiency, R6 on how fast flake melts in a 22 mm bore.
- **R16** (part repeatability) cannot be assessed until hardware exists (TRL 4, outside the current phase).

### Proposed, awaiting Amish

Update 2026-09-25: Amish accepted all recommendations (MMD-DDR-002). Items 1 to 10 are decided as marked below; item 8 was later superseded by the $500 figure.

1. **Drive:** (a) simple lever, (b) rack and pinion from a 1 t arbor press on a taller column, (c) screw press. Recommendation: (b), with (c) as a variant for small, thick parts. **Decided by Amish, 2026-09-25: go with recommendation.**
2. **Layout:** vertical barrel with the mold below. Recommendation: vertical. **Decided by Amish, 2026-09-25: go with recommendation.**
3. **Injection:** plunger rather than a reciprocating screw for the first build. **Decided by Amish, 2026-09-25: go with recommendation.**
4. **Heating:** two PID zones (barrel and nozzle), about $15 more than one zone. Recommendation: two zones. **Decided by Amish, 2026-09-25: go with recommendation.**
5. **Mold clamping:** bolted two-plate molds on a screw lift table now; a toggle clamp frame (about $40 more) as an upgrade. **Decided by Amish, 2026-09-25: go with recommendation.**
6. **Pressure indication:** a 10 kN load cell under the ram (about $30) rather than a spring-scale reading on the handle. **Decided by Amish, 2026-09-25: go with recommendation.**
7. **First mold:** a 64 x 50 x 6 mm test plaque; product molds after co-design. **Decided by Amish, 2026-09-25: go with recommendation.**
8. **Budget:** (a) keep $400 and count molds as tooling outside the machine budget; (b) raise to about $500 to include one mold; (c) drop the load cell and nozzle zone to reach about $450 with a mold. Recommendation: (a). `project.yaml` stays at $400 until Amish decides. **Decided by Amish, 2026-09-25: go with recommendation.**
9. **Fume control:** add a small hood and duct fan (about $40 to $60) at TRL 3, and keep a written condition to operate under extraction or outdoors. Recommendation: both. **Decided by Amish, 2026-09-25: go with recommendation.**
10. **First co-design partner:** a Precious Plastic workspace, a waste picker cooperative or a technical college. Recommendation: a group that already shreds HDPE or PP. **Decided by Amish, 2026-09-25: go with recommendation.**

### Safety concerns

- Molten plastic at up to 260 °C under pressure can spit from the nozzle or parting line; the nozzle and mold zone need a shield, which the concept does not yet show.
- Fumes: PVC and unknown plastics must never be heated; overheated PS releases styrene. Extraction is not yet in the design (R13).
- Mains-voltage band heaters on a steel frame: earthing, a fused inlet, an RCD or GFCI supply and an independent thermal cut-out are required, with wiring done or checked by a qualified electrician.
- The handle and rack store force and can pinch; a handle stop is needed.
- Recycled parts of unknown history must not be sold for food contact, young children's toys, medical or safety-critical use.

### Gaps and notes

- The session's web search budget was used up before this repo, so sources were checked by fetching pages directly. Figures that could not be verified were left out: commercial bench-top press specifications, the ram travel of 1 t arbor presses, and a cited fact for the Latin America row of the README table.
- Material property values (HDPE melt density, heat capacity, heat of fusion) are typical handbook values stated as estimates, to be sourced in the TRL 3 calculation note.

### Recommended next step

Review this note and the media. If approved, run `/advance-trl3` to calculate the drive force and efficiency, plunger clearance, melt soak time, heater and insulation sizing, and bolt clamp limits; choose a specific arbor press and confirm its ram travel; add a nozzle shield and fume hood; and produce the parametric model and drawing sheet.

## Session 2026-09-25: TRL 3

Amish asked for this batch of repos to be taken through the usual process with the instruction "you know the drill, nothing gets past TRL 3". He has not reviewed this repo's TRL 2 items one by one, so every item with a recommendation is adopted as recommended for TRL 3 under Amish's 2026-09-25 instruction, open for his review. This session ran `/advance-trl3` on that basis and stopped at TRL 3.

### What was done

- `docs/decisions/0001-trl2-review-decisions.md` (MMD-DDR-001 v0.1, status proposed): ten items adopted as recommended for TRL 3 (D1 to D10), two left open (O1, O2).
- `docs/04-calcs/01-sizing.md` (MMD-CAL-001 v0.1) and `docs/04-calcs/sizing.py`: shot size and mold stack, drive and ratchet, structure at design and overload, mold clamp, fill pressure through the nozzle and sprue, plunger clearance, heat (warm-up, losses, skin, load cell), melt soak, mold heat and cycle, power and energy, fume hood, mass, cost, and a status for every requirement. The script imports the model's parameters and reads the BOM and `project.yaml`; every number in the note is printed by it.
- `cad/src/model.py`: parametric build123d model of the press (16 modeled BOM items) with the vertical stack derived from the parameters. Exports `cad/step/` and `cad/stl/` for `micromold-assembly`, `barrel-set` and `mold-set`.
- `cad/src/sheets.py` and `cad/drawings/MMD-DWG-001.svg`, `.pdf`, `.png`: general arrangement at Rev P1, 1:10, marked "CONCEPT, NOT FOR FABRICATION" and "PRELIMINARY, NOT FOR FABRICATION". MMD-DWG-001 was free because the concept blueprint is MMD-DWG-010. To fit 1:10, the top view is placed beside the right view and labeled "relocated".
- `bom/bom.csv` (17 lines, all priced with a supplier type, $585.00) and `bom/bom-notes.md`.
- `cad/src/concept_media.py` now builds from the model; all of `media/` was re-rendered and every image checked. The cutaway now cuts on the injection axis (a project-side wrapper; the kit is unchanged), because the kit's cutter sat about 20 mm behind the axis and showed the barrel whole.
- MMD-PRB-001, MMD-PRC-001 and MMD-REQ-001 revised to v0.3; `README.md` and `project.yaml` (`trl: 3`, `trl_target: 3`, evidence list) updated. PDFs rebuilt in `docs/pdf/`.

Design changes found necessary by the calculations, applied for TRL 3 within the adopted items and open for Amish's review: a 450 mm ratchet handle on the pinion (one pull moves the plunger only about 31 mm, and a shot needs 120 mm); a 4 mm nozzle orifice and a sprue tapering from 5 to 7 mm (the 3 mm nozzle needed up to 12.1 MPa to fill); a 10 mm G-11 spacer under the load cell (otherwise about 94 °C); a 20 mm bracket plate on four mica pads (a 10 mm plate yields at overload); a perforated nozzle zone shield; the nozzle tip raised from 152 to 190 mm so that 120 mm mold stacks fit; a 255 mm ram; M10 x 110 mold bolts; and a pinned floating coupling on the plunger.

### Requirement status (MMD-CAL-001, Table 4)

2 not met, 3 at risk, 6 met on paper, 4 met by design, 1 not verifiable at TRL 3.

| ID | Status | Key number |
| --- | --- | --- |
| R14 Affordable | **Not met** | Press $495 against $400 (redefined scope, molds as tooling); $585 with one mold against the same $400 |
| R9 Bench size and mass | **Not met** (mass) | 38.5 kg against 35 kg, with an assumed 8 kg arbor press head; footprint 320 x 260 mm and handle 1,089 mm met |
| R2 Shot size | At risk | 34.2 g ideal; about 25 g if the fresh charge is not tamped with the press |
| R5 Warm-up | At risk | 14.8 min against 15 min |
| R6 Throughput | At risk | 9.4 parts per hour, but the mold settles at about 92 °C in still air |
| R3, R7, R8, R10, R11, R13 | Met on paper | 8.9 MPa at 250 N (11 % margin; fill needs 4.8 MPa); 45 cm²; $90 mold; 635 W; skin 48 °C; 124 m³/h hood |
| R1, R4, R12, R15 | Met by design | Safe resins; two PID zones with limits; electrical features; only the barrel and molds machined |
| R16 Repeatable parts | Not verifiable at TRL 3 | Needs hardware |

Key numbers: 22.5:1 drive, 3.8 ratchet pulls per shot; 13.2 kN and 34.7 MPa if an operator hangs 700 N on the handle (1.35 times the press rating); column 96.6 MPa and bracket 117 MPa at that overload; 103 W standing losses; about 21 Wh per shot.

### Decisions recorded (MMD-DDR-001)

Decided by Amish, 2026-09-25: go with recommendation (MMD-DDR-002; recorded at the time as adopted for TRL 3 and open for his review): D1 rack-and-pinion drive from a 1 t arbor press, screw press as a variant; D2 vertical barrel, mold below; D3 plunger injection; D4 two PID zones; D5 bolted two-plate molds on a screw lift table, toggle clamp later; D6 10 kN load cell; D7 test plaque first; D8 keep $400 with molds as tooling outside the machine budget (applied as a redefinition of R14; `budget_usd` unchanged, no new figure was recommended); D9 side hood with duct fan plus a written condition to run under it or outdoors; D10 first co-design partner to be a group that already shreds HDPE or PP. No pitch or problem rewording was recommended, so none was applied. MicroMold uses none of the batch's shared components, so no cross-repo interface applies.

### Still awaiting Amish

1. **O1, the specific first co-design partner and its city or region.** No recommendation was made.
2. **O2, first product molds after the test plaque.** For co-design; no recommendation was made.
3. **New, budget (R14).** Options: (a) raise `budget_usd` to $500 for the press, molds still as tooling; (b) count the fume extraction ($48) as workshop equipment outside the budget, which leaves the press at $447, still over; (c) drop the load cell and the ratchet, which would break R3's pressure reading and the shot. Recommendation: (a). Not applied; `budget_usd` stays at $400. **Decided by Amish, 2026-09-25: go with recommendation** (applied, MMD-DDR-002).
4. **New, mass target (R9).** Options: (a) relax to 40 kg for a bench-bolted press; (b) keep 35 kg and lighten the base plate, bracket and clamp. Recommendation: (a), after the head mass of a real press is known. Not applied. **Decided by Amish, 2026-09-25: go with recommendation** (applied, MMD-DDR-002).
5. **New, heater rating (R5).** Recommendation: two 300 W bands instead of 250 W, giving 12.2 min (700 W in all, R10 still met). Not applied. **Decided by Amish, 2026-09-25: go with recommendation** (applied, MMD-DDR-002).
6. **New, mold cooling (R6).** Recommendation: a small fan at the mold cooling station, which keeps the mold near 47 °C. Not applied. **Decided by Amish, 2026-09-25: go with recommendation** (applied, MMD-DDR-002).
7. **New, feedstock grade (R1).** Recommendation: add to R1 that flake comes from injection-molded items (caps, crates, buckets), because bottle-grade HDPE would need about 24 MPa. Not applied. **Decided by Amish, 2026-09-25: go with recommendation** (applied, MMD-DDR-002).

### Safety concerns

- Overload: body weight on the handle takes the press to 1.35 times its rating and about 35 MPa of melt pressure, enough to open the test mold's parting line and spit melt. The shield is essential, and a handle stop or pull limit is recommended before any build.
- The ratchet holds the ram under load; releasing the pawl can let the handle spring back.
- Fumes: capture from the nozzle zone relies on the plume rising to the side hood, which is assumed, not calculated. PVC and unknown plastics stay excluded.
- Hot funnel top (about 150 °C) is a working surface; gloves are required when loading.
- Mains heaters on a steel frame: earthing, fused inlet, RCD or GFCI and an independent cut-out remain required, with wiring done or checked by a qualified electrician.

### Gaps and notes

- Citations: WebFetch could not be used in this session (the fetch permission was not granted in time) and the WebSearch quota is exhausted, so the ram travel and head mass of 1 t arbor presses, commercial bench-top press figures and the Latin America fact in the README table remain unverified and are left out. Material and flow properties in MMD-CAL-001 are typical handbook values stated as assumptions, not cited.
- Kit cutaway: the kit cuts at the mean Y of the parts; `cad/src/concept_media.py` replaces it with a cut on Y = 0 so the bore shows.
- The hood is drawn floating beside the funnel; its bracket to the column is not modeled.
- Existing material beyond TRL 3: `build-log/README.md` (scaffold) is present, untouched and not extended. No test, build, firmware or PCB material exists.

### Recommended next step

TRL 4 is on hold by Amish's instruction; this repo stops at TRL 3. Amish's review is needed on the adopted items D1 to D10, the TRL 3 design changes and the new items 3 to 7 above, above all the budget and mass targets. For the record only, TRL 4 would need: a chosen arbor press with its ram measured, a built barrel, nozzle and test mold, a lab test report (TST, `environment: lab`) of warm-up, shot mass and repeatability (R16), melt pressure from the load cell, mold temperature over a run and fume capture, and build log entries. None of this has been started.

## Session 2026-09-25: recommendations accepted

Amish wrote, in chat on 2026-09-25: "i accept all your recommendations, go with them across all repos." Every MicroMold item with a recommendation is now "Decided by Amish, 2026-09-25: go with recommendation", recorded in `docs/decisions/0002-recommendations-accepted.md` (MMD-DDR-002 v0.1). Items without a recommendation stay open. `trl: 3` and `trl_target: 3` are unchanged.

### Decisions applied and what changed

- **D1 to D10 (MMD-DDR-001, now v0.2):** drive, layout, plunger injection, two PID zones, bolted molds on a lift table, load cell, test plaque, molds as tooling, side hood plus written condition, and a partner that already shreds HDPE or PP. Wording only; the design already followed them.
- **N1, budget:** `budget_usd` $400 to $500 in `project.yaml`; R14 target $400 to $500; README budget line updated.
- **N2, mass target:** R9 35 kg to 40 kg.
- **N3, heaters:** barrel bands 2 x 250 W to 2 x 300 W (BOM item 7, same price); warm-up 14.8 to 12.2 min; heaters 600 to 700 W.
- **N4, mold cooling:** new BOM item 18, a 120 mm mains axial fan on an angle bracket on the base plate ($12.00, 0.7 kg assumed), added to `cad/src/model.py`, STEP and STL, drawing MMD-DWG-001 (Rev P1 to P2) and all media. Mold about 92 to 47 °C; cycle 6.4 to 5.2 min (now soak limited); 9.4 to 11.6 parts per hour.
- **N5, feedstock:** R1 now requires flake from injection-molded items (caps, crates, buckets) and excludes bottle-grade HDPE.
- Knock-on numbers (MMD-CAL-001 v0.1 to v0.2): press cost $495 to $507, with one mold $585 to $597; mass 38.5 to 39.2 kg; connected load 635 to 753 W (5.3 to 6.3 A at 120 V); energy about 21 to 20 Wh per shot.
- Documents: MMD-PRB-001 v0.4, MMD-PRC-001 v0.4, MMD-REQ-001 v0.4, MMD-CAL-001 v0.2 (script `docs/04-calcs/sizing.py` updated), MMD-DDR-001 v0.2, new MMD-DDR-002 v0.1; `bom/bom-notes.md`; PDFs rebuilt.
- Also this session: every generated file re-rendered so the footer shows designmolecule.com; README "What sparked the idea" rewritten around the Hyatt brothers' 1872 plunger molding patent (US 133,229).

### Requirement status (MMD-CAL-001 v0.2)

1 not met, 2 at risk, 8 met on paper, 4 met by design, 1 not verifiable at TRL 3 (was 2, 3, 6, 4, 1).

| ID | Status | Key number |
| --- | --- | --- |
| R14 Affordable | **Not met** | $507 press against $500, over by $7 (the mold fan); $597 with one mold |
| R9 Bench size and mass | At risk | 39.2 kg against 40 kg, with an assumed 8 kg press head |
| R2 Shot size | At risk | 34.2 g ideal; about 25 g if the fresh charge is not tamped |
| R3, R5, R6, R7, R8, R10, R11, R13 | Met on paper | 8.9 MPa; 12.2 min; 11.6 per hour; 45 cm²; $90 mold; 753 W; skin 48 °C; 124 m³/h |
| R1, R4, R12, R15 | Met by design | Injection-grade flake only; two PID zones; electrical features; only barrel and molds machined |
| R16 Repeatable parts | Not verifiable at TRL 3 | Needs hardware |

### Still awaiting Amish

1. **O1:** the specific first co-design partner and its city or region. No recommendation.
2. **O2:** first product molds after the test plaque. No recommendation.
3. **O3 (new):** the press is $507 against $500. Options: (a) raise `budget_usd` to $520; (b) keep $500 and recheck against real quotations at TRL 4, since $7 is within the accuracy of indicative prices; (c) count the mold cooling fan as workshop equipment outside the press budget, as the molds are. Recommendation: (b). **Decided by Amish, 2026-09-26: `budget_usd` $520 (option (a)); see "Session 2026-09-26: budget approved".**

### Cross-repo actions

None. MicroMold uses none of the shared components, and no decision needs another repo to change.

### Safety concerns

- The mold cooling fan adds a mains-voltage fan beside the hot zone: keep its finger guard, route its lead away from the barrel and nozzle, and earth its bracket.
- Unchanged: overload on the handle (about 35 MPa), the ratchet holding the ram under load, fume capture assumed rather than calculated, and mains heaters. A handle stop or pull limit is still recommended before any build.

### TRL 4

TRL 4 remains on hold by Amish's instruction. Decided but on hold: recruiting the co-design partner (D10), choosing and weighing a real arbor press to confirm the head mass behind R9 (N2), and any build, purchase or trial of the press, heaters or fan. No test, build, firmware or PCB material was created.

## Session 2026-09-26: sources strengthened

- README, "By country or region": the uncited "Latin America (Brazil, Colombia)" row is replaced by a Brazil row citing the National Solid Waste Policy, Law 12,305 of 2010, on the official Planalto site (arts. 36 and 42: priority for cooperatives of low-income waste pickers and federal support for their equipment). Colombia is dropped because no source was verified for it.
- README, South Asia row: the uncited reference to large informal recycling sectors is removed.
- README, burning platform: the OECD 9 % recycling figure now also cites the OECD February 2022 press release, which states the figure directly; wording trimmed to what that release says.
- All other README links (World Bank *What a Waste 3.0*, Basel Convention, NEMA, US EPA, Precious Plastic Academy, US Patent 133,229) were fetched and confirmed. "What sparked the idea" unchanged; it already rests on the patent record.
- No controlled document changed; no budget change (O3 remains open).

## Session 2026-09-26: budget approved

Amish wrote, in chat on 2026-09-26: "i approve all the budget items." O3 is decided: budget set to $520 to cover the priced BOM (MMD-DDR-002 v0.2).

- `project.yaml` `budget_usd` $500 to $520; README budget and cost lines updated.
- R14 target $500 to $520; status **not met to at risk** ($507 press, $13 or 2.5 % margin on indicative prices; $597 with one mold, the mold being tooling).
- Requirement counts (MMD-CAL-001 v0.3): 0 not met, 3 at risk, 8 met on paper, 4 met by design, 1 not verifiable (was 1, 2, 8, 4, 1).
- Documents: MMD-PRB-001 v0.5, MMD-PRC-001 v0.5, MMD-REQ-001 v0.5, MMD-CAL-001 v0.3 (`sizing.py` now reports the margin when under budget), MMD-DDR-002 v0.2; `bom/bom-notes.md`; PDFs rebuilt. No media shows the budget, so none was regenerated.

## Session 2026-09-26: product appearance model and photoreal renders

Amish chose MicroMold on 2026-09-26 for the first batch of product renders, in the style of a product-design portfolio shot: finished-product geometry, studio lighting and a light seamless background.

### What was added

- `cad/src/product_model.py`: an appearance model for photoreal renders, built on `PARAMS`, `derived()` and `build_parts()` in `cad/src/model.py`. It exposes `product_parts()` (84 parts: 64 shell, 10 internal, 9 accessory, 1 context), `TITLE` and `RENDER_VIEWS` (hero and exploded). It adds:
  - Fillets on the base plate, column tube, press head, bracket, lift table, mold plates, control box and fan frame.
  - Fasteners: bench bolts and washers, gib screws with lock nuts on the head, a pinion shaft nut, M10 mold bolts with washers and nuts, heater clamp screws and fan bracket bolts.
  - Rack teeth on the ram, a ratchet head with a reversing lever, a ribbed rubber grip and a ball knob on the handle.
  - A visible mold parting line with pry slots, a sprue bushing seat and a stamp; nut slots in the lift table; guide rods and bushes on the screw jack; rubber grips on the tommy bar.
  - Mica band heaters with clamp lugs and ceramic terminal blocks; a nozzle with a radiused tip and its heater band; the jacket as an aluminum skin inside a slotted steel guard.
  - Perforated sides and a perforated window in the nozzle zone shield, hinges, a latch knob and a hot-surface warning label.
  - The fume hood with a face lip, round duct stub, band clamp and a short run of flexible duct; the cooling fan with blades, finger guard and bracket.
  - The control box with two lit PID controllers (process and set values), a lit force display for the load cell, a lit mains rocker switch, a cut-out reset button, a name plate, side vents, glands and a rear inlet; heater wiring in glass-fiber sleeving (fabric material) and a load cell lead.
  - Accessories: a tray of recycled flake and three molded test plaques. Context: a compact section of workbench top.
- `README.md`: hero image now points to `media/render-hero.png`, with a link to `media/render-exploded.png`. The render files are produced separately by the render pipeline.

### Differences from model.py

Each is appearance only; none changes a main dimension or interface.

1. **Fume duct.** `model.py` shows a square 100 mm massing block for the duct stub. The appearance model uses a round 100 mm duct stub of the same height with a band clamp, then a short run of flexible duct bending toward the back, cut short, because the inline fan and its 3 m of duct (BOM 17) have no position in the model. Proposed, awaiting Amish. Recommendation: accept for renders; place the inline fan in `model.py` only if a later layout needs it.
2. **Guide rods.** BOM 11 lists two guide rods that `model.py` does not model. The appearance model shows them under the lift table at X = ±62 mm with bushes on the base plate. Proposed, awaiting Amish. Recommendation: accept; confirm their positions when the clamp is detailed.
3. **Shield window.** `model.py` leaves the window opening in the shield front empty so the mold shows. The appearance model fills it with the perforated panel that BOM 16 specifies (10 mm square holes), so the mold is partly hidden in the hero render. Proposed, awaiting Amish. Recommendation: keep the perforated panel, since it is the safety guard as specified.
4. **Mold bolts.** `model.py` shows only the bolt heads. The appearance model shows full M10 bolts with washers, hex heads and nuts in slots in the lift table; the head top sits at the same height. Proposed, awaiting Amish. Recommendation: accept.
5. **Control box front.** The two PID envelopes are kept. A force display, mains rocker switch and cut-out reset button are added below them, in the box front, from BOM 4 and BOM 13. Proposed, awaiting Amish. Recommendation: accept; the panel layout is illustrative.
6. **Display values.** The lit readouts show illustrative set points (210 °C barrel, 225 °C nozzle) and 0.00 kN force with the plunger raised. These are not recommendations. Proposed, awaiting Amish. Recommendation: accept as illustrative.

### Status

This is an appearance model only: no tolerances, no fabrication detail and no change to `model.py`, the BOM or the controlled documents. `trl` stays 3, and TRL 4 remains on hold by Amish's instruction.

## Session 2026-09-27: kit 1.5.0 and image quality

- Kit 1.5.0 synced: STANDARDS v1.5 (sections 12 to 15: product renders, storefront images and image quality, public release, authorship and signing), `.kit/cards.py`, `.kit/image_qc.py`, `.kit/release_gate.py`, issue templates, and the `/render-product` and `/release` commands. `CLAUDE.md` now matches `.kit/CLAUDE.md`.
- Every `media/render-*.png` recaptioned from its original render with the new layout: the title, concept label and repository sit in a band above the render and the view note in a band below it, each line wrapped to the image width, so no text overlaps other text or the render or runs off the image. `media/card.png` and `media/social-preview.png` regenerated with the same rules.
- `python .kit/image_qc.py` and `python .kit/release_gate.py` pass. trl stays 3.

## Session 2026-10-01: kit 1.7.0, constructable design and prototype build plan

Amish approved the build plan format on 2026-09-30 and asked for it across all repos, with outstanding decisions kept in a separate register. He also wrote: "If you are realising that the design cannot be built as per concept - fix the design assumptions to match and be physically feasible as you draw the illustrations." This session brought MicroMold to that standard. Nothing was built or bought; `trl` stays 3.

### What was done

- Kit 1.7.0 installed (`.kit/`, `.claude/commands/`); `CLAUDE.md` replaced by `.kit/CLAUDE.md`.
- Constructability review with build123d checks: `cad/src/model.py` rewritten as separate components (`build_components()`), grouped by BOM line for the existing media (`build_parts()`), with `python cad/src/model.py --check`: 155 checks (no unintended overlap, every joint touching, clearances, full stroke, table at both ends of travel, assembly order, a process and BOM line for every part). All pass.
- `docs/decisions/0003-design-for-construction.md` (MMD-DDR-003 v0.1, Draft): every change, made under Amish's 2026-09-30 instruction to make the design physically buildable; open for his review.
- `bom/bom.csv` (19 lines; line 19 added) and `bom/bom-notes.md`; `docs/04-calcs/sizing.py` and MMD-CAL-001 v0.4 (mass, heights, heat, cost against the value-engineering target); MMD-REQ-001 v0.6; MMD-PRC-001 v0.6; `README.md` (links line, "Building the prototype"); `project.yaml` (`design_state: constructable`, new evidence).
- STEP and STL regenerated; general arrangement MMD-DWG-001 Rev P4; concept media regenerated from the new model.
- `cad/src/build_plan_media.py`: overview, base plate hole layout, 14 making sketches (MMD-DWG-101 to 114), 11 joint close-ups and 14 assembly step pictures.
- `docs/05-build-plan.md` (MMD-BLD-001 v0.1) and `docs/06-design-decisions.md` (MMD-DEC-001 v0.1). PDFs rebuilt in `docs/pdf/`.

### Design changes made for construction (MMD-DDR-003)

1. Press head: cut from its frame and bolted to an 8 mm head plate welded to the column, four M10 countersunk screws reached through holes in the column (it overlapped the column by 30 mm, with no fixing).
2. Barrel bracket: a 20 mm shelf welded to the column face plus an 8 mm back plate welded up the column corners (it cut into the 3 mm wall and was fixed only to it); mica pads now in the stack.
3. Barrel flange 100 mm with four M8 cap screws; funnel 64 mm (was 80 mm) so the screws can be reached.
4. Nozzle screws into an M30 x 1.5 thread in the barrel; spherical tip in a 2 mm spherical seat in the mold (test mold table now at 102 mm).
5. Jacket made as two half shells hung on four tabs, spacers and M5 screws (it floated, and as one sleeve could not be fitted with the barrel in place).
6. Load cell, 56 mm G-11 spacer and a drilled plunger coupling on screws that never cross the spacer; ball-lock pin for the plunger (stack 5 mm taller; handle top 1,094 mm).
7. Screw lift: a Tr20 screw welded under the table, turned by a handwheel nut on the base plate, dropping through a hole in the bench; the column face stops the table turning (the concept's 100 mm jack could not fit in 50 mm).
8. Mold: M10 cap screws into thread inserts, two dowels; sprue taper turned the right way.
9. Shield sides on folded feet screwed to the base; front on two hinges and a latch.
10. Mold fan on a plate bracket with an intake hole; fan 4 mm closer to the mold.
11. Hood held by an L-shaped arm on rivnuts in the column.
12. Heater wiring rerouted over the shield.
13. Ratchet adapter made from the press's lever hub with a welded 1/2 in square drive.
14. Base plate 8 mm (was 12 mm) and head and back plates 8 mm, keeping mass under 40 kg.
15. Assembly order fixed: barrel in from above before the press head; band heaters clamp on after; plunger unit fitted as one piece.

### Key results

- Mass 39.0 kg against 40 kg (R9 at risk; head mass assumed). Handle top 1,094 mm (R9 met on height).
- Value-engineering target: USD 520. Estimated cost of the constructable design: USD 544 for the press (USD 24 over the target); USD 638 with the test mold. The construction parts added USD 37.
- Warm-up 12.3 min (was 12.2 min); other results unchanged. Counts: none not met, 2 at risk (R2, R9), 8 met on paper, 4 met by design, 1 not verifiable at TRL 3, R14 over the value-engineering target.

### Proposed, awaiting Amish

All in the design decisions register (MMD-DEC-001): accept the changes above; how flake is loaded with only 8 mm between the raised plunger and the funnel (recommend lifting the plunger out on its ball-lock pin); the hole through the bench for the lift screw; a handle stop or torque-limiting socket; and the earlier open items (partner, product molds, appearance model differences).

### Stale media (made on Amish's Mac, not regenerated here)

The design changed visibly, so these need redoing with `/render-product` after `cad/src/product_model.py` is updated: `media/render-hero.png`, `media/render-exploded.png` (and any other `media/render-*.png`), `media/card.png` and `media/social-preview.png`. They show the concept's head position, 80 mm flange and funnel, the screw jack block with a front crank, mold bolts with nuts, guide rods, and the old fan bracket.

### Safety concerns

- Overload on the handle is still unlimited (about 35 MPa at 700 N); a torque-limiting socket is recommended (register item 4).
- Loading flake with the plunger lifted out means handling a plunger whose top end is about 94 °C; heat-resistant gloves are required.
- The barrel is fitted from above and the press weighs 39 kg: two people to lift it, and the bench must be drilled.

### Recommended next step

Amish reviews MMD-DDR-003 and the register. TRL 4 (buying the arbor press, confirming the items listed for purchase, building and testing) stays on hold.

## Session 2026-10-02: open decisions decided

Amish, 2026-10-02: "i approve your recommendations for all 555 open decisions." This approves the recommendation written for each open decision in the design decisions register (MMD-DEC-001 v0.1). trl stays 3; no build or test work was done, and the model, BOM quantities and prices, and pictures are unchanged.

### Decisions recorded

Seven decisions, all moved to Decisions made in MMD-DEC-001, dated 2026-10-02:

1. MMD-DDR-003 accepted, P1 to P15, with one condition: P1 (cutting the head from the arbor press casting and tapping four M10 holes in its back) is confirmed against the bought press before it is cut.
2. Loading: option (a), lift the plunger out on its ball-lock pin to load, with a simple plunger rest on the column so the hot plunger is never laid on the bench.
3. Lift screw: option (a), a 25 mm hole through the bench.
4. Overload: option (b), a torque-limiting socket on the ratchet adapter, set so the ram cannot exceed the press rating, checked against the load cell at TRL 4.
5. First co-design partner: a community plastic recycling workspace that already shreds HDPE or PP; a Precious Plastic workspace near Irving, Texas, is the first candidate to approach.
6. First product mold: a flat, single-cavity part of 25 g or less that fits the 120 x 90 mm plates, such as a coaster, tile or cable clip, chosen with the partner.
7. Appearance model: accept differences 1, 3, 5 and 6; update 2 and 4 to the constructable design and add the screw lift, flange and fan bracket at the same time.

### Documents changed

- `docs/06-design-decisions.md` (MMD-DEC-001 v0.2): open decisions moved to Decisions made; the 2026-09-30 row updated.
- `docs/decisions/0003-design-for-construction.md` (MMD-DDR-003 v0.2, status Draft): accepted with the P1 condition; A1 to A3 accepted, with the plunger rest added to A1; consequence added.
- `docs/decisions/0001-trl2-review-decisions.md` (MMD-DDR-001 v0.3) and `docs/decisions/0002-recommendations-accepted.md` (MMD-DDR-002 v0.3): O1 and O2 recorded as decided.
- `docs/02-concept.md` (MMD-PRC-001 v0.7): loading step with the plunger rest; pressure safety rule (torque-limiting socket replaces "fit a handle stop or a pull limit"); a hot plunger safety note; first product mold; first candidate partner.
- `docs/01-problem.md` (MMD-PRB-001 v0.6): first candidate partner.

### Follow-up actions to carry approved decisions into the design

1. Decision 1 (model and drawings): before cutting, check the bought press head against P1 (casting thickness behind the four M10 holes, 20 mm thread depth) and revise `cad/src/model.py` and MMD-DWG-001 if it differs.
2. Decision 2 (model, BOM, build plan pictures): add the plunger rest on the column to the model, a BOM line, the build plan (component, joint and step pictures) and its loading step.
3. Decision 4 (model, BOM, build plan pictures, calculations): add the torque-limiting socket to the ratchet adapter in the model and the BOM, set its torque in MMD-CAL-001 from the press rating, and update build plan section 3.6 and safety stop S4.
4. Decision 6 (drawings): sketch the first product mold (flat, single cavity, 25 g or less, on the 120 x 90 mm plates) once the partner picks the part.
5. Decision 7 (pictures): update `cad/src/product_model.py` (no guide rods; cap screws into inserts; the screw lift, flange and fan bracket as built) and re-render the photoreal renders, card and social preview on Amish's Mac.

### Points found in the review

- Value engineering counts moving the duct fan and duct (USD 48) into shared workshop extraction as a saving that brings the press to USD 496; that removes cost from scope rather than saving it, so it does not compare like with like with the USD 520 target.
- Overload protection (decision 4) had been recommended since TRL 3 and is still not in the model or BOM; it must be added before any build (follow-up 3).

## Session 2026-10-02: approved follow-ups carried out

Amish, 2026-10-02, approved that every follow-up action from the open-decision sign-off be carried out. trl stays 3; no build or test work was done. Documents changed, with new versions: MMD-CAL-001 v0.5, MMD-REQ-001 v0.7, MMD-PRC-001 v0.8, MMD-BLD-001 v0.2, MMD-DEC-001 v0.3; also `bom/bom.csv` and `bom/bom-notes.md`, `README.md`, `cad/src/model.py`, `docs/04-calcs/sizing.py`, `cad/src/build_plan_media.py`, `cad/src/sheets.py` (MMD-DWG-001 Rev P5), `cad/src/concept_media.py` and `cad/src/product_model.py`.

### Approved follow-ups carried out

1. **Decision 1, check the bought head against P1: not done in full.** The bought press does not exist yet (buying it is TRL 4, on hold). On paper: the model now checks the nominal values the head must have (10 mm of casting between each M10 hole and the ram bore, 21 mm hole depth for a 20 mm thread in a 140 mm deep head), and build plan section 3.5 has a step to check the bought head before the cut and to stop if it differs. The model and drawing MMD-DWG-102 are revised only if the bought head differs.
2. **Decision 2, plunger rest: done.** Plunger rest on the column's right wall in the model (cup 32 mm across, plate on two M6 rivnuts, 400 mm above the bench, with the rested plunger checked for clearance); BOM line 20 (USD 6, estimate by parts); making sketch MMD-DWG-115, joint 12, step 12 and the loading routine in build plan section 3.16; the column sketch MMD-DWG-102 gained the right-wall rivnut holes.
3. **Decision 4, torque-limiting socket: done.** Socket between the ratchet adapter and the ratchet in the model (BOM line 21, USD 40, estimate at the midpoint of a USD 30 to 50 retail band). Torque set in MMD-CAL-001 section B: the press reaches its rating at 234 N m, the socket is set to 180 N m (198 N m at plus 10 per cent), which limits the ram to 8.3 kN (0.85 times the rating) and the melt to 21.8 MPa; the script stops if a setting would let the ram pass the rating. Build plan section 3.6, step 7, safety stops S3 and S4 and the first checks table updated. Checking the setting against the load cell is TRL 4.
4. **Decision 6, sketch of the first product mold: not done.** It waits for the partner to choose the part (outreach by Amish).
5. **Decision 7, appearance model: done.** `cad/src/product_model.py` updated: guide rods, screw jack and tommy bar removed; lift table with its welded Tr20 screw, handwheel nut and thrust washer; M10 cap screws into inserts, no nuts; shelf, back plate, mica pads and flange screws, head plate and screws, coupling, fan bracket and screws, hood arm, torque-limiting socket and plunger rest as built. Render scenes exported (hero, exploded) to `/home/claude/renders/micromold`. The photoreal renders, card and social preview are made on Amish's Mac next.

### Key results

- Requirement status changes: none. R9 stays at risk (39.8 kg against 40 kg, was 39.0 kg); R14 stays over the value-engineering target.
- Value-engineering target: USD 520. Estimated cost of the constructable design: USD 590 (USD 70 over the target); USD 684 with the test mold. The two lines added USD 46.
- Model: 186 constructability checks pass (was 155). STEP and STL regenerated.
- Pictures regenerated: MMD-DWG-001 (Rev P5), MMD-DWG-102, 108 and 115 (new), joint 12 (new), overview, steps 7 to 14, concept media (hero, cutaway, exploded, flow, blueprint, viewer).
- Appearance deviations of the appearance model from the model (2 and 4 of the 2026-09-26 list) are now removed; items 1, 3, 5 and 6 stay accepted.

### Cross-repo actions

None for this repo from the follow-up list.

### Points for Amish

- Mass is 0.2 kg under the 40 kg target; any real arbor press head heavier than the assumed 8 kg takes R9 to not met.
- The torque setting of 180 N m is a paper figure from the press rating at an assumed 0.84 efficiency; it is confirmed against the load cell at TRL 4.

## 2026-10-02: photoreal renders redone on the constructable design

Rendered with Blender Cycles on Amish's Mac from the updated appearance model; captioned with `.kit/photo_caption.py`; `media/card.png` and `media/social-preview.png` regenerated with `.kit/cards.py`. Views: hero, exploded. image_qc passes. Appearance deviations are those logged above as proposed, awaiting Amish.

## 2026-10-03: decisions recorded

Amish decided on 2026-10-03: "TIght Margins - i accept the margins". For MicroMold this is the 180 N m torque-limiting socket setting and the R9 mass margin of 0.2 kg (39.8 kg against 40 kg, with an assumed 8 kg press head).

- `docs/06-design-decisions.md` (MMD-DEC-001) and `docs/03-requirements.md` (MMD-REQ-001) updated.

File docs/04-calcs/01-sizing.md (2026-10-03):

---
doc_id: MMD-CAL-001
title: MicroMold sizing calculations
project: MicroMold
doc_type: Calculation
version: "0.5"
status: Draft
date: '2026-10-02'
author: Amish Chadha
license: CERN-OHL-S-2.0
revisions:
- version: "0.1"
  date: '2026-09-25'
  author: Amish Chadha
  change: First issue for TRL 3 (shot size, drive and ratchet, structure, mold clamp, fill pressure, plunger clearance, heat, melt soak and cycle, power, fume hood, mass, cost)
- version: "0.2"
  date: '2026-09-25'
  author: Amish Chadha
  change: Recommendations accepted by Amish (DDR-002)
- version: "0.3"
  date: '2026-09-26'
  author: Amish Chadha
  change: Budget approved by Amish ($520, MMD-DDR-002); R14 from not met to at risk
- version: "0.4"
  date: '2026-10-01'
  author: Amish Chadha
  change: "Constructable design (MMD-DDR-003): mass, heights, heat and cost updated; budget treated as a value-engineering target"
- version: "0.5"
  date: '2026-10-02'
  author: Amish Chadha
  change: Decisions of 2026-10-02 carried in - torque-limiting socket set to 180 N m from the press rating (overload now 8.3 kN, B4a and B4b), plunger rest, BOM 21 lines, mass 39.8 kg, press USD 590
---

# MicroMold sizing calculations

On paper, MicroMold meets twelve of its sixteen requirements (eight by calculation, four by design), has two at risk, misses none, is over its value-engineering target on cost and leaves one requirement that only hardware can show. Version 0.5 carries the decisions Amish approved on 2026-10-02: a torque-limiting socket set to 180 N m on the ratchet adapter, which caps the overload at 8.3 kN, and a plunger rest on the column. Version 0.4 followed the constructable design of MMD-DDR-003 (2026-10-01): plates and fixings added, an 8 mm base plate, a 100 mm flange, a screw lift with a handwheel nut and a plunger coupling. This issue includes the decisions Amish made on 2026-09-25 (MMD-DDR-002): a 40 kg mass target, two 300 W barrel bands, a mold cooling fan and injection-grade feedstock in R1. On 2026-09-26 Amish approved a `budget_usd` of $520 to cover the priced BOM (MMD-DDR-002). `budget_usd` is a hypothetical value-engineering target, not a limit (Amish, 2026-10-01). Value-engineering target: USD 520. Estimated cost of the constructable design: USD 590 (USD 70 over the target) for the press, and USD 684 with the first mold, which is tooling (R14). The two at risk are mass (R9, 39.8 kg against 40 kg with an assumed 8 kg arbor press head) and shot size (R2, if the fresh charge is not tamped). The 300 W bands bring warm-up to 12.3 min (R5), and the fan keeps the mold near 47 °C, so throughput (R6) is 11.6 parts per hour, limited by melt soak. The v0.1 calculations also showed that the TRL 2 concept could not work as drawn: a single pull of the arbor press handle moves the plunger only about 31 mm, not the 120 mm a shot needs, so a ratchet handle drives the pinion. Five more changes followed: a 4 mm nozzle orifice with a tapered sprue, a glass-epoxy spacer that keeps the load cell cool, a 20 mm bracket plate on mica pads, a nozzle zone shield, and a nozzle tip raised to 190 mm so that 120 mm mold stacks fit. Every number in this note is printed by `docs/04-calcs/sizing.py`; the tag in brackets, for example [B5], is the line of that script's output that carries it.

> **Safety:** These are first-principles estimates for a paper proof of concept. They do not replace a pressure and electrical safety review of a built press. The barrel, nozzle and mold reach 180 to 260 °C, the melt is under pressure, the heaters run at mains voltage and without the torque-limiting socket an operator can load the press to about 1.35 times its rating; with it set to 180 N m the limit is 0.85 times. See MMD-PRC-001, Safety.

## Scope and method

The note checks every requirement in MMD-REQ-001 v0.7 against the design in MMD-PRC-001 v0.8 and the parametric model `cad/src/model.py`. The script imports the model's `PARAMS` and `derived()` stack-up, so the bore, stroke, nozzle height, table travel, bracket, mold and hood used here are those in the STEP files and in drawing MMD-DWG-001. It also reads `bom/bom.csv` and `budget_usd` in `project.yaml`. Run it from the repo root with `python docs/04-calcs/sizing.py`.

The design case is the reference part of MMD-REQ-001: a 30 g HDPE test plaque, 64 x 50 x 6 mm, molded from washed, dried flake of 3 to 8 mm at a 220 °C barrel set point in a 25 °C workshop.

## Assumptions

*Table 1. Main assumptions.*

| Area | Assumption | Basis |
| --- | --- | --- |
| HDPE properties | Melt density 0.75 g/cm³, solid 0.95 g/cm³; cp 2.3 kJ/(kg K); 205 kJ/kg to melt the crystalline fraction; melt conductivity 0.25 W/(m K); tamped flake 0.12 W/(m K) at 450 kg/m³; diffusivity 0.11 mm²/s for part cooling | Typical handbook values; estimates to confirm for the chosen feedstock |
| Melt flow | Power law, n = 0.40, 150 Pa s at 1,000 s⁻¹ (K = 9,464 Pa sⁿ) at 210 °C, typical of injection-grade HDPE; 1,000 Pa s at low shear for leakage | Estimate; bottle-grade HDPE is several times more viscous |
| Drive | 450 mm handle on a 20 mm pinion pitch radius; design efficiency 0.60 (TRL 2 value); friction 0.15 for the journal and ram guide; mesh 0.95 | Arbor press dimensions to confirm on the chosen press |
| Operator | 250 N design pull; 700 N when the operator hangs body weight on the handle, limited to the socket's 180 N m (+10 % tolerance, about 440 N); a comfortable ratchet pull of 90° (from 30° above horizontal to 60° below) | Ergonomic judgment |
| Structure | S235 steel, yield 235 MPa, 85 % of yield at 220 °C; E 200 GPa steel, 69 GPa aluminum | Handbook |
| Mold clamp | Four M10 class 8.8 bolts (58 mm², proof 600 MPa) at 20 kN preload each; factor 2 against opening | As at TRL 2 |
| Heat | Combined convection and radiation 10 W/(m² K) in still air, 30 W/(m² K) with a fan; mineral wool 0.045 W/(m K); mica 0.5 W/(m K); G-11 glass-epoxy 0.30 W/(m K); steel cp 0.49 kJ/(kg K); a factor of 1.2 on warm-up for PID approach and heater lag | Handbook ranges |
| Cycle | Ejection at 95 °C; step times in Table 3 | Estimates, to be timed later |
| Fume capture | Flanged side hood, capture velocity 0.40 m/s at 100 mm from the funnel axis (low-velocity release into quiet air) | Common design range for hoods |
| Mass | Arbor press head, ram and ratchet 8.0 kg; jacket 1.0 kg; lift screw and handwheel nut 1.0 kg; plunger rest 0.3 kg; torque-limiting socket 0.6 kg (assumed); hood on the press 0.6 kg; mold cooling fan and bracket 0.7 kg; hardware 1.0 kg | Assumed; the head mass depends on the chosen press |

## A. Shot size and mold stack (R2, R7)

- **Swept volume.** The 22 mm plunger has 380.1 mm² of area. Of the 150 mm stroke, the first 30 mm clears the funnel and 120 mm is in the bore, sweeping 45.6 cm³ [A1], or 34.2 g of HDPE melt, 14 % above the 30 g target [A2].
- **Reservoir.** At full stroke 140 mm of bore (53.2 cm³, 40 g) stays below the plunger tip, so the barrel holds 2.2 shots [A3], and each charge soaks for about two cycles before it is injected.
- **Compaction eats stroke.** Only 15 mm of stroke is spare once 30 g has been delivered. If the fresh charge on top is still loose flake at 0.55 g/cm³ when the operator injects, compacting it takes about 32 mm and the shot falls to about 25 g [A4]. Tamping each top-up with the press while loading is therefore part of the process, and R2 is **at risk** until a trial shows the charge is dense enough.
- **Mold stack.** With the nozzle tip at 190 mm and a lift table that travels from 60 to 160 mm, mold stacks from 30 to 120 mm fit with 10 mm to drop clear of the nozzle; the 90 mm test mold sits at 102 mm, because the nozzle tip seats 2 mm deep in the mold's spherical seat [A5]. The TRL 2 layout, with the nozzle at 152 mm, could not take a 120 mm stack.
- **Mold footprint.** The column face is 65 mm behind the axis, so molds up to 120 mm deep across Y fit, and a 150 x 120 mm mold goes in with its long side along X [A6].

## B. Drive, force and the ratchet (R3, R2)

- **Ratio and efficiency.** The handle and pinion give 22.5:1. Friction losses at the mesh, the pinion journals and the ram guide give an efficiency of about 0.84; the design keeps the TRL 2 value of 0.60 as a margin for a worn or dirty press [B1].
- **Pressure.** At 250 N on the handle the plunger force is 3.38 kN and the melt pressure 8.9 MPa (89 bar, 1,288 psi) at 0.60 efficiency, or 4.71 kN and 12.4 MPa at 0.84 [B2]. R3 (8 MPa) needs an efficiency of 0.54, a margin of 11 % at the design value [B3].
- **Overload.** Without a limiter, an operator hanging 700 N of body weight on the handle produces 13.2 kN, 1.35 times the 1 t rating of the press [B4]. A torque-limiting socket on the ratchet adapter (decided by Amish, 2026-10-02) removes that case. The press reaches its rating at 234 N m at the pinion (9.8 kN at 0.84 efficiency and a 20 mm pitch radius); the socket is set to 180 N m, 77 % of that, or 198 N m at its worst tolerance of plus 10 % [B4a]. The ram force is then at most 8.3 kN and the melt pressure 21.8 MPa, 0.85 times the press rating and 0.83 of the load cell's 10 kN range; the socket slips at a pull of about 400 N on the 450 mm handle, while the 250 N working pull is 62 % of the setting and does not trip it [B4b]. Sections C and D size the parts for this limited case. The setting is checked against the load cell at TRL 4.
- **Stroke per pull (finding).** Filling the 120 mm of bore turns the pinion 344° and moves the grip 2.70 m. One comfortable 90° pull moves the plunger 31.4 mm, so a shot takes 3.8 pulls [B5]. No single sweep of a 450 mm handle can deliver the shot; the TRL 2 statement that "a steady pull drives the plunger 120 to 150 mm" was wrong. The work confirms it: at full pressure a shot needs 405 J at the melt and 675 J at the handle, while one 90° pull at 250 N gives 177 J [B6].
- **Change.** A 1/2 in drive ratchet handle, 450 mm long, on a socket fitted to the pinion shaft replaces the press's fixed handle (BOM item 2, about $25), with the torque-limiting socket (BOM item 21, about $40) between the adapter and the ratchet. The pawl holds the ram between pulls, so the melt stays under pressure while the operator resets. This is within the rack-and-pinion drive (MMD-DDR-001 D1), decided by Amish on 2026-09-25.

## C. Structure and overload

- **Barrel.** The thick-walled barrel (42 mm OD, 22 mm bore) sees a hoop stress of 1.76 times the melt pressure: 15.6 MPa at design and 38.3 MPa at the torque limit, a factor of 5.2 on 85 % of yield at 220 °C [C1].
- **Column.** The barrel axis is 95 mm in front of the column center, so the 80 x 60 x 3 mm tube carries a bending moment between the bracket and the drive head: 34.5 MPa at 4.71 kN (factor 6.8) and 60.7 MPa at the 8.3 kN torque limit (factor 3.9; 96.6 MPa, factor 2.4, at 13.2 kN without the socket) [C2, C3]. The frame opens about 0.31 mm at the ram in use, over the 358 mm between the shelf and the pinion [C4], so the plunger joins the load cell through a pinned floating coupling and is guided only by the bore.
- **Bracket (change).** The bracket cantilevers 65 mm from the column face. A 10 mm plate, as in the TRL 2 BOM, reaches 167 MPa in use (factor 1.4) and would reach 294 MPa at the torque limit (factor 0.8), above yield. A 20 mm plate gives 42 MPa in use and 74 MPa at the torque limit, a factor of 3.2 [C5a, C5b, C6a, C6b]. BOM item 9 is now a 20 mm plate.
- **Plunger and load cell.** Plunger buckling is not a concern (567 kN, 68 times the force at the torque limit) [C7]. The 10 kN load cell sees 4.71 kN in use and 8.3 kN at the torque limit, inside its rated range; without the socket it would see 13.2 kN, above the range but inside the 150 % safe overload typical of such cells [C8].

## D. Mold clamp (R7)

- **Bolts.** Four M10 class 8.8 bolts at 20 kN preload each (57 % of proof) need about 40 N m of torque [D1].
- **Area.** With a factor of 2 at 8.9 MPa the bolts hold 45 cm² of projected area, against the 40 cm² target; the 32 cm² plaque pushes the plates apart with 28.4 kN [D2]. R7 is met on paper.
- **Overload.** At the torque limit (21.8 MPa) the plaque pushes with 70 kN against 80 kN of preload, so the parting line should stay shut, and each bolt carries 17.5 kN, below its proof load [D3]. Without the socket, 34.7 MPa would push with 111 kN and the parting line would flash and spit melt. The nozzle zone shield is still there for a failure of the limit.
- **Plates.** The 45 mm plates bend 11 µm between bolt rows, at 22 MPa, below the 20 to 30 µm at which HDPE starts to flash [D4].

## E. Fill pressure through the nozzle and sprue (R3)

*Table 2. Pressure needed to fill the plaque [E1 to E4].*

| Nozzle orifice | Sprue | Fill time | Nozzle | Sprue | Cavity | Total | Available at 250 N |
| --- | --- | --- | --- | --- | --- | --- | --- |
| 3 mm (TRL 2) | 4 to 6 mm | 3 s | 4.6 MPa | 6.7 MPa | 0.9 MPa | 12.1 MPa | 8.9 MPa |
| 3 mm (TRL 2) | 4 to 6 mm | 10 s | 2.8 MPa | 4.1 MPa | 0.5 MPa | 7.5 MPa | 8.9 MPa |
| 4 mm | 5 to 7 mm | 10 s | 1.5 MPa | 2.8 MPa | 0.5 MPa | 4.8 MPa | 8.9 MPa |
| 4 mm | 5 to 7 mm | 20 s | 1.1 MPa | 2.1 MPa | 0.4 MPa | 3.6 MPa | 8.9 MPa |

- **Change.** A shear-thinning melt needs almost as much pressure for a slow fill as for a fast one, so the TRL 2 nozzle left little margin. A 4 mm orifice and a sprue tapering from 5 to 7 mm bring a 10 s hand fill down to 4.8 MPa, about half the pressure available. BOM items 8 and 12 are updated.
- **Pauses.** A 6 mm sprue core in a 50 °C mold takes about 25 s to freeze, so the pauses of about 1 s between ratchet pulls do not stop the fill [E5].
- **Feedstock.** HDPE from blow-molded bottles (melt flow index below 1) is about five times as viscous and would need about 24 MPa, beyond the press [E6]. Flake from injection-molded items (caps, crates, buckets) suits it; R1 now requires it (MMD-DDR-002).

## F. Plunger clearance

- **Backflow.** At 8.9 MPa over 30 mm of seal, a diametral clearance of 0.05 mm leaks 1 mm³ during a 30 s hold, 0.10 mm leaks 6 mm³ and 0.20 mm leaks 51 mm³, all negligible against a 45,600 mm³ shot [F5, F10, F20]. The charge above the melt also seals the gap.
- **Fit.** The hot bore grows about 32 µm more than a plunger at 100 °C, so the gap opens as the barrel heats. A cold diametral clearance of 0.05 to 0.10 mm is recommended; 22 H8/f7 gives 0.020 to 0.074 mm [F9]. This answers the TRL 2 open question on clearance.

## G. Heat: warm-up, losses, skin and load cell (R5, R11, R4)

- **Heat to store.** The barrel zone holds 2.05 kg of barrel, about 0.72 kg of flange and funnel and 0.30 kg of heaters, and needs 342 kJ to reach 220 °C including 40 g of cold plastic and the mineral wool [G1].
- **Jacket.** 217 mm of 25 mm mineral wool loses 17 W, with the skin at 48 °C at a 220 °C set point [G2]. R11's 60 °C limit is met on paper for the jacket.
- **Standing losses.** At 220 °C: jacket 18 W, funnel 18 W, nozzle 21 W, bracket heat break 35 W through four mica pads (0.25 W/K) and plunger 12 W, 103 W in all [G3]. The TRL 2 figure was about 80 W.
- **Warm-up.** With two 300 W bands (MMD-DDR-002) the barrel zone reaches 220 °C in 12.3 min and the nozzle zone in 6.6 min [G4]. R5 (15 min) is met on paper. The 250 W bands of v0.1 would take 14.9 min, 2.7 min longer [G4b].
- **Heater loading.** The 300 W bands run at 4.5 W/cm², well inside the roughly 7.7 W/cm² (50 W/in²) usual for mica bands [G5].
- **Load cell (change).** The plunger behaves as a fin: with its tip at 150 °C its top end reaches about 94 °C, too hot for a strain-gauge load cell. A 10 mm G-11 glass-epoxy spacer (88 K/W) under the cell keeps it at about 27 °C [G6]. The spacer is added to BOM item 4 (about $5).
- **Temperature control (R4).** Two PID loops with a 150 to 260 °C set range, a set point limit and an independent 280 °C cut-out meet R4 by design; the ±5 °C hold needs a test later.

## H. Melt soak, mold heat and cycle (R6)

- **Soak.** For the center of a 22 mm column to reach 180 °C with the wall at 220 °C takes 7.5 min as melt and 9.3 min as tamped flake [H1]. Each charge soaks for about two cycles, so cycles shorter than about 5 min would starve the melt.
- **Mold heat (finding).** Each shot puts 19.5 kJ into the 2.62 kg aluminum mold, 54 W at 6 min cycles. In still air the mold settles at about 92 °C and the 6 mm plaque needs 2.1 min to cool to 95 °C [H2]. With the mold cooling fan (BOM item 18, MMD-DDR-002) blowing on it through the shield side it settles at about 47 °C and needs 0.8 min [H3].

*Table 3. Cycle steps [H4, H5].*

| Step | Time |
| --- | --- |
| Load and tamp the fresh charge | 1.0 min |
| Bolt the mold and raise the table | 0.75 min |
| Inject in four ratchet pulls | 0.25 min |
| Hold | 0.5 min |
| Cool in the mold | 0.8 min (fan) or 2.1 min (still air, v0.1) |
| Lower, unbolt, open and eject | 1.0 min |
| Clean and reassemble | 0.75 min |
| **Cycle** | **5.1 min (fan), 5.2 min with the soak limit; 6.4 min (still air)** |

- **Throughput.** In still air the cycle would be 6.4 min, 9.4 parts per hour, with the plaque leaving a 92 °C mold barely below its ejection temperature [H4]. With the fan the cooling steps allow 5.1 min, but each fresh charge must soak about two cycles for 9.3 min, so the design cycle is 5.2 min, 11.6 parts per hour, with the mold near 47 °C [H5, H6]. R6 (8 per hour) is met on paper.

## I. Power and energy (R10)

- **Load.** 700 W of heaters, a 25 W duct fan, an 18 W mold fan and about 10 W of controls give 753 W: 3.3 A at 230 V and 6.3 A at 120 V [I1]. R10 is met on paper.
- **Energy.** A shot takes 6.3 Wh into the plastic and 13.4 Wh of losses and auxiliaries over a 5.2 min cycle, about 20 Wh, or 0.66 kWh per kg of parts [I2]. The barrel zone runs at about 26 % duty [I3].

## J. Fume hood (R13)

A flanged side hood with a 150 x 100 mm face, 100 mm from the funnel axis, needs about 124 m³/h for a capture velocity of 0.40 m/s; in a 100 mm duct that is 4.4 m/s [J1]. A 100 mm inline duct fan rated 170 m³/h or more of free air covers this with margin for 3 m of flexible duct. Fumes from the nozzle rise inside the shield and along the warm jacket to the hood; that path is assumed, not calculated. With the set point limit of 260 °C in both controllers and the written condition to run only under the hood or outdoors, R13 is met on paper.

## K. Mass and size (R9)

- **Mass (at risk).** Base plate 5.2 kg (8 mm, MMD-DDR-003), column 5.7 kg, arbor press head, ram and ratchet 8.0 kg (assumed), shelf 2.6 kg, barrel set and heaters 3.4 kg, plunger and load cell 1.0 kg, jacket and guard 1.0 kg, lift table plate 2.0 kg, mold set 3.0 kg, shield 0.9 kg, hood 0.6 kg, mold cooling fan and bracket 0.7 kg and hardware 1.0 kg, plus the parts added for construction: head mounting plate and screws 1.2 kg, shelf back plate 0.8 kg, plunger coupling, pin and spacer 0.3 kg, ratchet adapter 0.1 kg, lift screw and handwheel nut 1.0 kg, hood arm 0.2 kg, shield feet, hinges and latch 0.2 kg, jacket hangers 0.1 kg, plunger rest 0.3 kg and the torque-limiting socket 0.6 kg (assumed): 39.8 kg without the control box [K1], 0.2 kg under the 40 kg target set by MMD-DDR-002 (99 % of it) [K3]. With the head mass still assumed, R9 is **at risk**. The TRL 2 figure of 32 kg left out the bracket, the table and the mold bolts and had a lighter bracket.
- **Size.** The footprint is 320 x 260 mm and the handle reaches 1,094 mm above the bench at the highest start of a pull; the ram top is at 1,020 mm [K2]. Both meet R9.

## L. Cost (R14, R8)

The BOM has 21 lines, all priced: $684.00 with one mold, of which the press is $590.00, the test mold $94.00 and the fume extraction $48.00 [L1]. `budget_usd` is a hypothetical value-engineering target, not a spending limit (Amish, 2026-10-01; $520 since 2026-09-26, MMD-DDR-002):

- **Value-engineering target: USD 520. Estimated cost of the constructable design: USD 590 (USD 70 over the target)**, the press alone with molds counted as tooling [L2]. R14 is over the value-engineering target; the cost drivers and savings worth trying are in the design decisions register (MMD-DEC-001).
- **Press and one mold:** $684.00, $164.00 over the target; the mold is tooling outside it [L2].
- Without the fume extraction the press would be $542.00 [L2].

The mold at $94.00 meets R8 ($100) on an indicative price. MMD-DDR-002 added the mold cooling fan ($12.00, item 18). MMD-DDR-003 added $37.00 of parts for construction (line 19, the shelf back plate and cap screws, the shield's hinges and latch) and $4.00 of mold screws, inserts and dowels. The decisions of 2026-10-02 added $46.00: the plunger rest (line 20, $6.00, an estimate by parts: tube and flat bar offcuts about $3, two M6 rivnuts and screws about $2, welding and cutting about $1) and the torque-limiting socket (line 21, $40.00, an estimate at the midpoint of a $30 to $50 retail band for a 1/2 in drive torque limiter).

## M. Results against every requirement

*Table 4. Requirement status from this note [M].*

| ID | Requirement | Value | Target | Status |
| --- | --- | --- | --- | --- |
| R14 | Affordable | $590 press, $70 over the target; $684 with one mold | Press at or under the $520 value-engineering target, molds as tooling | **Over the value-engineering target** |
| R9 | Bench size and mass | 320 x 260 mm; 1,094 mm; 39.8 kg | 350 x 300 mm; 1.1 m; 40 kg | **At risk** (mass) |
| R2 | Shot size | 34.2 g ideal; about 25 g if the fresh charge is loose flake | 30 g or more | **At risk** |
| R3 | Injection pressure | 8.9 MPa at 0.60 efficiency (12.4 MPa at 0.84); fill needs about 4.8 MPa in 10 s | 8 MPa at 250 N or less | Met on paper |
| R5 | Warm-up | 12.3 min (barrel zone, 2 x 300 W) | 15 min or less | Met on paper |
| R6 | Throughput | 11.6 per hour with the mold fan, mold about 47 °C | 8 per hour or more | Met on paper |
| R7 | Mold envelope | 45 cm² at 8.9 MPa; stacks 30 to 120 mm; 170 x 126 mm table | 150 x 120 mm, 40 to 120 mm stack, 40 cm² | Met on paper |
| R8 | Low-cost tooling | $94 (indicative) | $100 or less | Met on paper |
| R10 | Power supply | 753 W; 6.3 A at 120 V | 1 kW or less; 10 A or less at 120 V | Met on paper |
| R11 | Touch-safe surfaces | Jacket skin 48 °C; nozzle zone shield added | 60 °C or less; nozzle and mold zone guarded | Met on paper |
| R13 | Fume control | Hood and fan, 124 m³/h; set point limit 260 °C | Exhaust hood or outdoors; set points above 260 °C blocked | Met on paper |
| R1 | Safe thermoplastics | HDPE, PP, LDPE and PS within 150 to 260 °C from injection-molded items; PVC and bottle-grade HDPE excluded by label and procedure | Four resins, injection grade; PVC excluded | Met by design |
| R4 | Temperature control | Two PID zones, 150 to 260 °C set range, set point limit, 280 °C cut-out | 150 to 260 °C, ±5 °C; cut-out above 280 °C | Met by design |
| R12 | Electrical safety | Earthed frame, fused inlet, double-pole switch, RCD or GFCI, 250 °C wiring | As listed | Met by design |
| R15 | Garage-buildable | Only the barrel set and molds need a lathe or mill (local shop) | Hand tools, drill press, optional welding | Met by design |
| R16 | Repeatable parts | Needs hardware | Mass within ±3 % over 10 shots | Not verifiable at TRL 3 |

Counts: 0 not met, 2 at risk, 8 met on paper, 4 met by design, 1 not verifiable at TRL 3; R14 over the value-engineering target.
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

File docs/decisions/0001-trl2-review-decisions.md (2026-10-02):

---
doc_id: MMD-DDR-001
title: MicroMold TRL 2 review decisions
project: MicroMold
doc_type: Design decision record
version: "0.3"
status: Draft
date: '2026-10-02'
author: Amish Chadha
license: CERN-OHL-S-2.0
revisions:
- version: "0.1"
  date: '2026-09-25'
  author: Amish Chadha
  change: Record the TRL 2 review items adopted as recommended for TRL 3 under Amish's 2026-09-25 instruction, and the items that remain open
- version: "0.2"
  date: '2026-09-25'
  author: Amish Chadha
  change: Recommendations accepted by Amish (DDR-002)
- version: "0.3"
  date: '2026-10-02'
  author: Amish Chadha
  change: O1 and O2 decided by Amish on 2026-10-02 as recommended
---
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

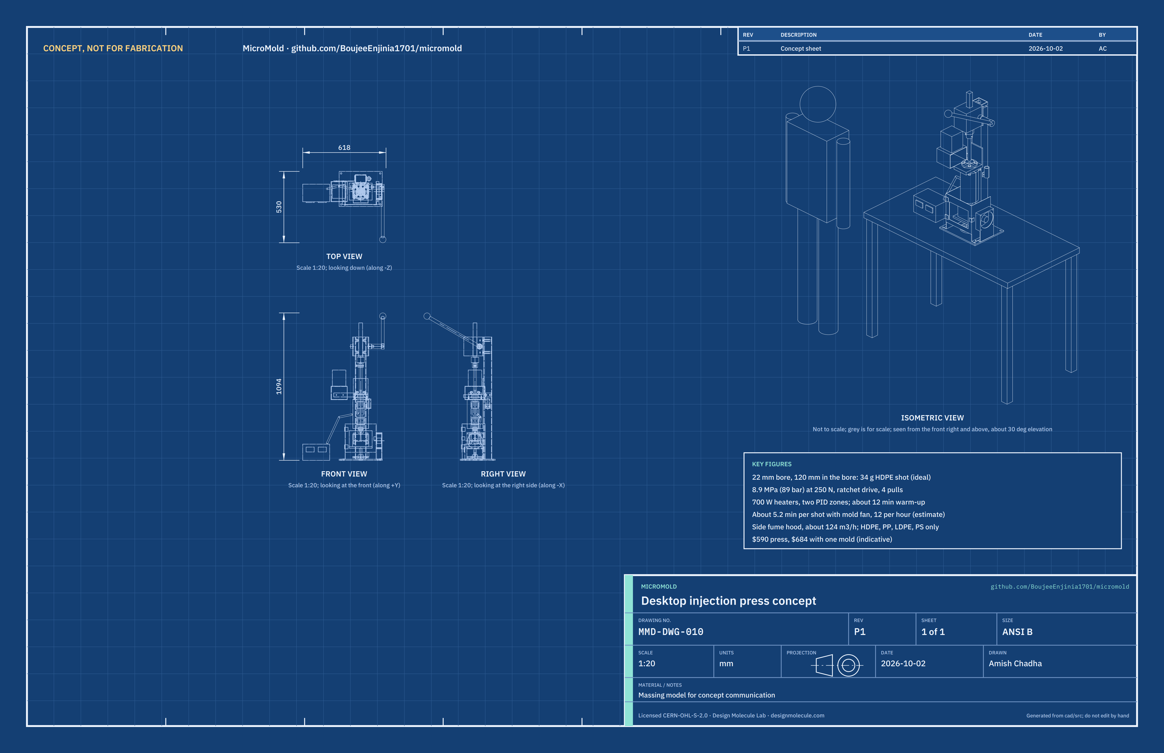
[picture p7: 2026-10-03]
media/concept-blueprint.png

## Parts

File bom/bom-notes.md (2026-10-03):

# BOM notes

Costs are indicative USD prices for TRL 3, not quotations. Every line has a unit cost and a supplier or supplier type. Checked against `budget_usd`, a hypothetical value-engineering target (not a limit), in MMD-CAL-001, section L.

- Line numbers match the callouts in `media/exploded.png` and Table 1 of MMD-PRC-001. Item 15 (hardware) is not modeled.
- Total $684.00 with one mold; $590.00 for the press alone; $94.00 for the test plaque mold.
- Value-engineering target: USD 520. Estimated cost of the constructable design: USD 590 (USD 70 over the target), the press alone. Cost drivers and savings worth trying are in MMD-DEC-001.
- Changed by MMD-DDR-003 (design for construction, 2026-10-01): line 1 is 8 mm plate; lines 9, 10, 11, 12, 16, 17 and 18 respecified for the buildable design (shelf back plate and cap screws, split jacket and hangers, screw lift with handwheel nut, mold cap screws, inserts and dowels, shield feet, hinges and latch, hood arm, fan plate bracket); line 19 (construction parts, $30.00) added. Item 15 and line 19 hardware are not all modeled.
- Under MMD-DDR-001 D8 and MMD-DDR-002 (decided by Amish, 2026-09-25) the budget covers the press, molds are tooling (R8), and `budget_usd` is $520 (was $500, and $400 before that), approved by Amish on 2026-09-26 to cover the priced BOM. Since the decisions of 2026-10-02 the press is $70.00 over the target; with one mold the total is $164.00 over, the mold being tooling.
- Added by the decisions of 2026-10-02: line 20 (plunger rest, $6.00, estimate by parts: tube and flat bar offcuts about $3, two M6 rivnuts and screws about $2, welding and cutting about $1) and line 21 (torque-limiting socket, 1/2 in drive, set to 180 N m, $40.00, estimate at the midpoint of a $30 to $50 retail band for a preset or adjustable torque limiter). Both are modeled.
- Changed by MMD-DDR-002: the band heaters (item 7) are 300 W instead of 250 W at a similar price, and a mold cooling fan (item 18, $12.00) is added.
- Added at TRL 3 from the calculations: the ratchet handle and socket (in item 2), the G-11 spacer (in item 4), the 20 mm bracket plate and mica pads (item 9), the nozzle zone shield (item 16) and the fume hood and duct fan (item 17, MMD-DDR-001 D9). Together about $96.
- Line 3 (rack ram) comes with the arbor press in line 2 and has no separate cost. The ram must be 255 mm or longer with 150 mm of engaged travel; confirm on the chosen press.
- Heater and fan voltages must match the regional supply (230 V or 120 V).
- Feedstock is not in the BOM. Use flake from injection-molded items; bottle-grade HDPE is too stiff for a hand press (MMD-CAL-001, E6).

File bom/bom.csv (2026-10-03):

item | qty | spec | supplier | unit_cost_usd | make_buy | notes
1 Base plate | 1 | Steel plate 320 x 260 x 8 mm (S235 or A36), drilled for four bench bolts and the lift screw, tapped M6 for the shield feet and fan bracket; the column is welded to it | Local steel stockist (offcut and cutting) | 25.00 | make | Indicative price; 8 mm from MMD-DDR-003 (was 12 mm)
2 Column and drive head | 1 | 1 t arbor press (rack-and-pinion head, pinion shaft, about 20 mm pitch radius) on an 80 x 60 x 3 mm steel tube column 0.9 m; the press's fixed handle is replaced by a 1/2 in drive ratchet handle about 450 mm long on a socket fitted to the pinion shaft | Tool retailer (arbor press and ratchet) and steel stockist (tube) | 110.00 | buy | Indicative: press about $65, tube about $20, ratchet handle and socket about $25; ratchet added at TRL 3 (MMD-CAL-001 B); the head is cut from its frame and bolted to the head mounting plate (line 19, MMD-DDR-003); the ratchet fits on the torque-limiting socket (line 21), not directly on the adapter
3 Rack ram | 1 | 28 mm square rack ram, 255 mm or longer, 150 mm travel with the rack still engaged | Included with item 2 | 0.00 | buy | Included in item 2; ram length and travel to be confirmed on the chosen press
4 Plunger load cell | 1 | 10 kN (1 t) compression load cell with HX711 amplifier and 4-digit display; 10 mm glass-epoxy (G-11) thermal spacer under the cell | Electronics distributor; plastics stockist for the spacer | 35.00 | buy | Indicative: cell and display about $30; spacer about $5 (added at TRL 3)
5 Plunger | 1 | 22 mm ground steel rod, 200 mm, cross-drilled for a pinned floating coupling to the load cell | Bearing and linear motion supplier | 15.00 | buy | Indicative price; drilled on a drill press
6 Heated barrel | 1 | 42 mm steel bar, bored and honed to 22 mm, 260 mm long, with 80 mm flange and loading funnel | Local machine shop | 45.00 | make | Indicative price; lathe work
7 Band heater | 2 | 300 W mica band heater, 42 mm ID x 50 mm, mains voltage to suit region | Industrial heater supplier | 12.00 | buy | Indicative price, same size and similar price to the 250 W band; 300 W from MMD-DDR-002 (R5)
8 Nozzle and nozzle heater | 1 | Steel nozzle, 4 mm orifice, radiused tip; 100 W band heater | Local machine shop and industrial heater supplier | 20.00 | make | Indicative price; orifice 4 mm from TRL 3 (was 3 mm)
9 Barrel shelf and heat break | 1 | 20 mm steel shelf 110 x 150 mm and 8 mm back plate 110 x 120 mm, welded to the column; four mica pads 15 x 15 x 3 mm under the flange; four M8 x 30 cap screws with mica washers into tapped holes in the shelf | Local steel stockist and industrial heater supplier (mica) | 22.00 | make | Indicative price; plate thickened from 10 mm at TRL 3; back plate and cap screws from MMD-DDR-003
10 Insulation jacket and guard | 1 | 25 mm mineral wool, aluminum skin, perforated steel guard, made as two half shells; four hanger tabs and four M5 x 25 screws on 14 mm spacers into the shelf | Building supplier and sheet metal stockist | 20.00 | make | Indicative price; hangers from MMD-DDR-003
11 Mold clamp | 1 | Lift table 170 x 126 x 12 mm steel with a Tr20 x 4 screw 150 mm long welded in flush; 120 mm handwheel with a Tr20 x 4 nut fitted in its hub; 20 mm thrust washer; 100 mm travel; the screw drops through a 25 mm hole in the base plate and bench | Steel stockist, bearing and linear motion supplier, tool retailer (handwheel) | 30.00 | make | Indicative price; screw lift redesigned by MMD-DDR-003 (a 100 mm travel jack cannot fit under the table)
12 Aluminum mold set (tooling) | 1 | Two 6061 plates 120 x 90 x 45 mm, test plaque cavity, sprue 5 to 7 mm taper, 12.5 mm radius nozzle seat; four M10 x 70 class 8.8 cap screws into steel thread inserts in the lower plate; two 6 mm dowel pins | Local machine shop | 94.00 | make | Indicative price including CNC or manual milling; tooling outside the press value-engineering target (MMD-DDR-001 D8); screws, inserts and dowels from MMD-DDR-003
13 Control box | 1 | Two PID controllers with set point limit, two 25 A SSRs with heat sink, fused IEC inlet, double-pole switch, 280 °C independent thermal cut-out, fan outlet, earthed enclosure | Electronics distributor | 55.00 | buy | Indicative price
14 Heater and sensor wiring | 1 | 250 °C wire, glass-fiber sleeving, two K-type thermocouples, ferrules, earth leads | Electronics distributor | 20.00 | buy | Indicative price
15 Hardware and consumables | 1 | Bench bolts, M6 to M10 fasteners, anti-seize, labels | Hardware store | 15.00 | buy | Indicative price; not modeled
16 Nozzle zone shield | 1 | 1.5 mm perforated steel sheet: two sides with folded feet (two M6 screws each) and a front with a perforated window on two hinges with a latch, 230 x 170 mm plan | Sheet metal stockist | 18.00 | make | Indicative price; added at TRL 3 (R11); feet, hinges and latch from MMD-DDR-003
17 Fume hood and duct fan | 1 | Side hood 150 x 100 mm face in 1 mm aluminum; 100 mm inline duct fan rated 170 m³/h or more free air; 3 m of 100 mm aluminum flexible duct and clamps | Hardware store and ventilation supplier | 48.00 | buy | Indicative: fan about $30, hood about $8, duct about $10; added at TRL 3 (MMD-DDR-001 D9); held by the hood arm (line 19)
18 Mold cooling fan | 1 | 120 x 120 x 38 mm axial fan, mains voltage to suit region, about 18 W, with finger guard and power lead; 3 mm steel plate bracket with a 112 mm intake hole, four M4 screws, bolted to the base plate with two M6 screws, blowing on the mold through the shield side | Electronics distributor and steel stockist | 12.00 | buy | Indicative price; added by MMD-DDR-002 (R6); plugs into the control box fan outlet
19 Construction parts | 1 | Head mounting plate 120 x 140 x 8 mm steel with four M10 x 25 countersunk screws; plunger coupling drilled from 40 mm steel bar with a 6 mm ball-lock pin and six M5 screws; ratchet adapter from the press's lever hub with a welded 1/2 in square drive and a 6 mm roll pin; hood arm 30 x 5 mm flat bar with two M6 rivnuts and two M5 screws | Steel stockist, hardware store | 30.00 | make | Indicative price; parts added to make the design buildable (MMD-DDR-003)
20 Plunger rest | 1 | Plate 38 x 30 x 5 mm steel on two M6 rivnuts and screws in the column right wall, with a welded cup of 32 mm OD x 24 mm ID steel tube, 70 mm tall, on a 3 mm base disc; the plunger stands tip down in it when lifted out on its ball-lock pin | Steel stockist, hardware store | 6.00 | make | Estimate by parts: tube and flat bar offcuts about $3, two M6 rivnuts and screws about $2, welding and cutting from shop stock about $1; added by decision 2 of 2026-10-02 (hot plunger never laid on the bench)
21 Torque-limiting socket | 1 | 1/2 in drive torque-limiting socket (click or slip type), set to 180 N m (+/- 10 %), between the ratchet adapter (line 19) and the ratchet handle (line 2); rated at 200 N m or more | Tool retailer | 40.00 | buy | Estimate: retail price band of about $30 to $50 for a 1/2 in drive preset or adjustable torque limiter, midpoint taken; added by decision 4 of 2026-10-02 (the ram cannot exceed the 1 t press rating); torque set in MMD-CAL-001 section B; checked against the load cell at TRL 4

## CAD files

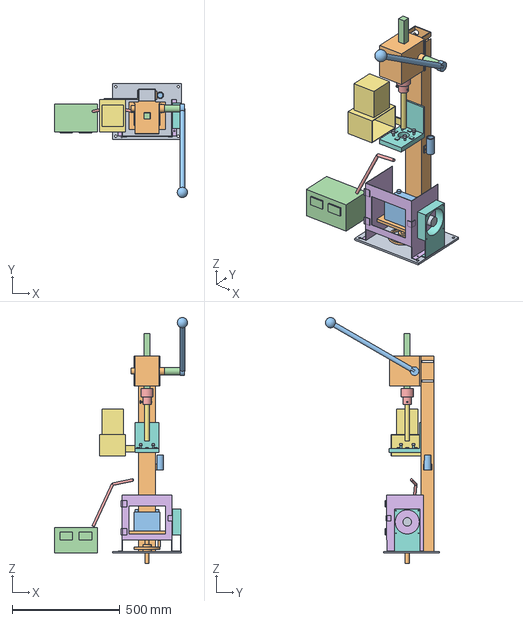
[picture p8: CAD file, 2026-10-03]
cad/step/micromold-assembly.step
618.0 x 529.6 x 1142.0 mm

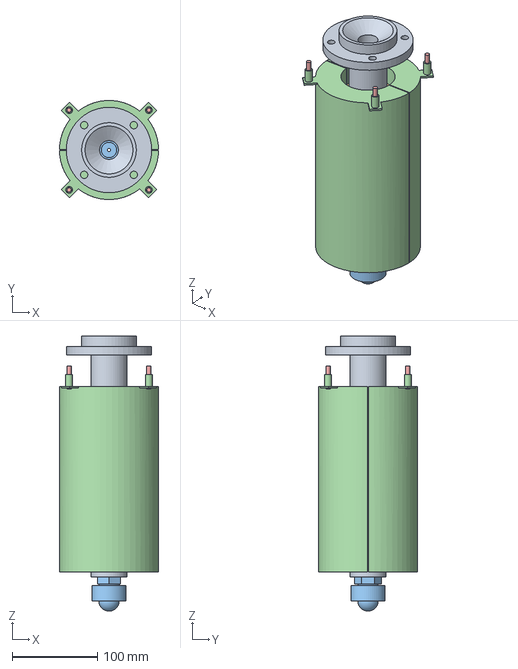
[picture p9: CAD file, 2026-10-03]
cad/step/barrel-set.step
116.0 x 115.8 x 321.8 mm

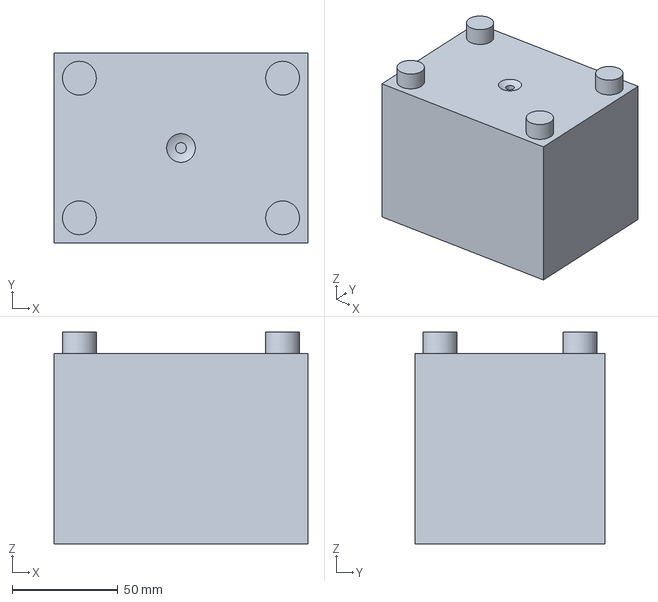
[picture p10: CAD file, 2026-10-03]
cad/step/mold-set.step
120.0 x 90.0 x 100.0 mm

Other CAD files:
cad/stl/barrel-set.stl
cad/stl/micromold-assembly.stl
cad/stl/mold-set.stl

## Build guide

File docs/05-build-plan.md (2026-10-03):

---
doc_id: MMD-BLD-001
title: MicroMold prototype build plan
project: MicroMold
doc_type: Build plan
version: "0.2"
status: Draft
date: '2026-10-02'
author: Amish Chadha
license: CERN-OHL-S-2.0
revisions:
  - version: "0.1"
    date: '2026-10-01'
    author: Amish Chadha
    change: First build plan, with pictures by component and step; design made constructable (MMD-DDR-003)
  - version: "0.2"
    date: '2026-10-02'
    author: Amish Chadha
    change: Approved decisions carried into the plan - plunger rest on the column (new section 3.16, joint 12, step 12), torque-limiting socket on the ratchet adapter (sections 3.6 and 6, step 7), a head check before cutting (section 3.5), figures 28 and 29, mass and cost updated
---

# MicroMold prototype build plan

**Plan, not yet built.** How to build the first proof-of-concept prototype, component by component. Building and testing to it is TRL 4 work. Decisions still to be made are kept in the design decisions register ([docs/06-design-decisions.md](06-design-decisions.md)), not here.

## 1. What you are building

Figure 1. Every component, pulled apart and numbered in build order

*Figure 1. Every component pulled apart and numbered in build order.*

The prototype is one bench-top MicroMold press: a steel column welded to a base plate, carrying the head of a 1 t arbor press at the top and a heated steel barrel on a shelf half way up. A ratchet handle, through a torque-limiting socket that slips before the press can be overloaded, turns the press's pinion, the rack ram pushes a 22 mm plunger down the barrel, and melt leaves a nozzle into a two-plate aluminium mold that a screw lift table holds up against it, inside a perforated shield. A fan cools the mold and a side hood draws fumes from the funnel. Figure 1 shows the 19 components in the order you make or fit them. The base plate, column weldment, lift table, jacket, shield, fan bracket, hood, arm and plunger rest are cut, drilled, folded and welded in a small workshop; the coupling, spacer and plunger need only a drill press; the barrel, nozzle and mold come from a local machine shop; the press head, handwheel and lever hub are bought and modified; the heaters, load cell, fans, torque-limiting socket, control box parts and fixings are bought. The parts cost about USD 590 for the press and USD 684 with the test mold, from the bill of materials.

> **Safety:** MicroMold runs mains-voltage heaters on a steel frame and holds molten plastic at up to 260 °C under pressure. All mains wiring must be done or checked by a qualified electrician to local code, with an earthed frame, a fused inlet, a double-pole switch, a 30 mA RCD (or GFCI) supply and an independent thermal cut-out. Wear heat-resistant gloves, long sleeves and eye protection at the hot zone, keep the shield shut while injecting, and heat only HDPE, PP, LDPE and PS, under the hood or outdoors; never PVC or unknown plastics. Welding needs a welding helmet, gloves and a fire-safe area. The finished press weighs about 40 kg: lift it with two people.

## 2. What changed to make it buildable

The concept showed what the press does; some of its parts could not be made or fixed as drawn. Each change below keeps what the press does, and all of them are recorded in decision record MMD-DDR-003, open for Amish's review.

*Table 1. Changes from the concept.*

| Component | The concept had | The buildable design has | Why |
| --- | --- | --- | --- |
| Arbor press head | A block overlapping the column by 30 mm, with no fixing | The head cut from its frame and bolted to a plate welded to the column front, four countersunk screws reached through holes in the column (Figure 9) | A 1 t arbor press is one casting; the plate carries the head's thrust into the column corners |
| Barrel bracket | A plate cutting into the column wall, fixed only to its thin front wall; no mica pads in the stack | A 20 mm shelf welded to the column face and a back plate welded up the column corners; four mica pads under the flange (Figure 14) | The thin tube wall would bend; the pads are the heat break the calculations count on |
| Barrel flange | No fixing; no room for screws inside the funnel | A 100 mm flange held by four M8 cap screws; the funnel 64 mm across instead of 80 mm (Figure 14) | A hex key reaches the screws past the funnel |
| Nozzle | Standing under the barrel, with no joint | Screwed into an M30 x 1.5 thread in the barrel end; a spherical tip that seats in the mold (Figure 13) | The nozzle comes out for cleaning; the seat locates and seals the mold |
| Jacket and guard | One sleeve floating round the barrel | Two half shells that close round the barrel, hung from the shelf on four tabs, spacers and M5 screws (Figure 16) | A one-piece sleeve cannot pass the nozzle once the barrel is in; the hangers hold it clear of the barrel and heaters |
| Load cell and plunger | Stacked with no fixings and no way to lift the plunger | A drilled coupling under a glass-epoxy spacer, with no screw crossing the spacer; the plunger hangs on a ball-lock pin (Figure 18) | Keeps the load cell's thermal break and lets the plunger float in line with the bore |
| Screw lift | A block with a crank and no mechanism, in a space too low for any 100 mm screw jack | A screw welded under the table, turned by a handwheel nut on the base plate, dropping through a hole in the bench (Figure 7) | The only screw lift that keeps the 60 to 160 mm table range and the 120 mm mold stack |
| Mold | Bolts with nuts under the lower plate, so it could not sit flat; no alignment | Cap screws into thread inserts; two dowels; the sprue taper turned the right way (Figure 27) | Sits flat on the table and closes the same way every time |
| Shield | Sides floating 52 mm above the bench; no hinge | Sides on folded feet screwed to the base plate; the front on two hinges and a latch (Figure 21) | A fixed guard; the handwheel is reached under the closed front |
| Fan bracket | Touching only the fan's lower edge | A plate with an intake hole, four screws through the fan's corners (Figure 23) | Holds the fan and lets it breathe |
| Fume hood | Floating beside the funnel | An L-shaped arm to the column on rivnuts (Figure 25) | A tube wall cannot be reached from inside |
| Loading | Only 8 mm between the raised plunger and the funnel, so no room to pour flake | The plunger lifts out of its coupling on the ball-lock pin and stands tip down in a rest on the column (Figures 28 and 29) | Flake goes straight into the funnel and the hot plunger is never laid on the bench |
| Overload | Nothing stopped a 700 N pull on the handle, which reaches 1.35 times the press rating | A torque-limiting socket set to 180 N·m between the ratchet adapter and the ratchet (section 3.6) | The socket slips at about a 400 N pull, so the ram cannot pass the press rating |
| Base plate | 12 mm | 8 mm | Keeps the press at 39.8 kg, under its 40 kg target, after the added plates and fixings; the base plate does not carry the injection force |

## 3. Making the components

Make and check each component before the assembly step that needs it. Sizes are in millimetres. "Front" is the operator's side; "left" and "right" are as seen by the operator. Workshop tolerance is 0.5 mm unless a step says otherwise; drawings do not carry tolerances before TRL 4.

### 3.1 Base plate

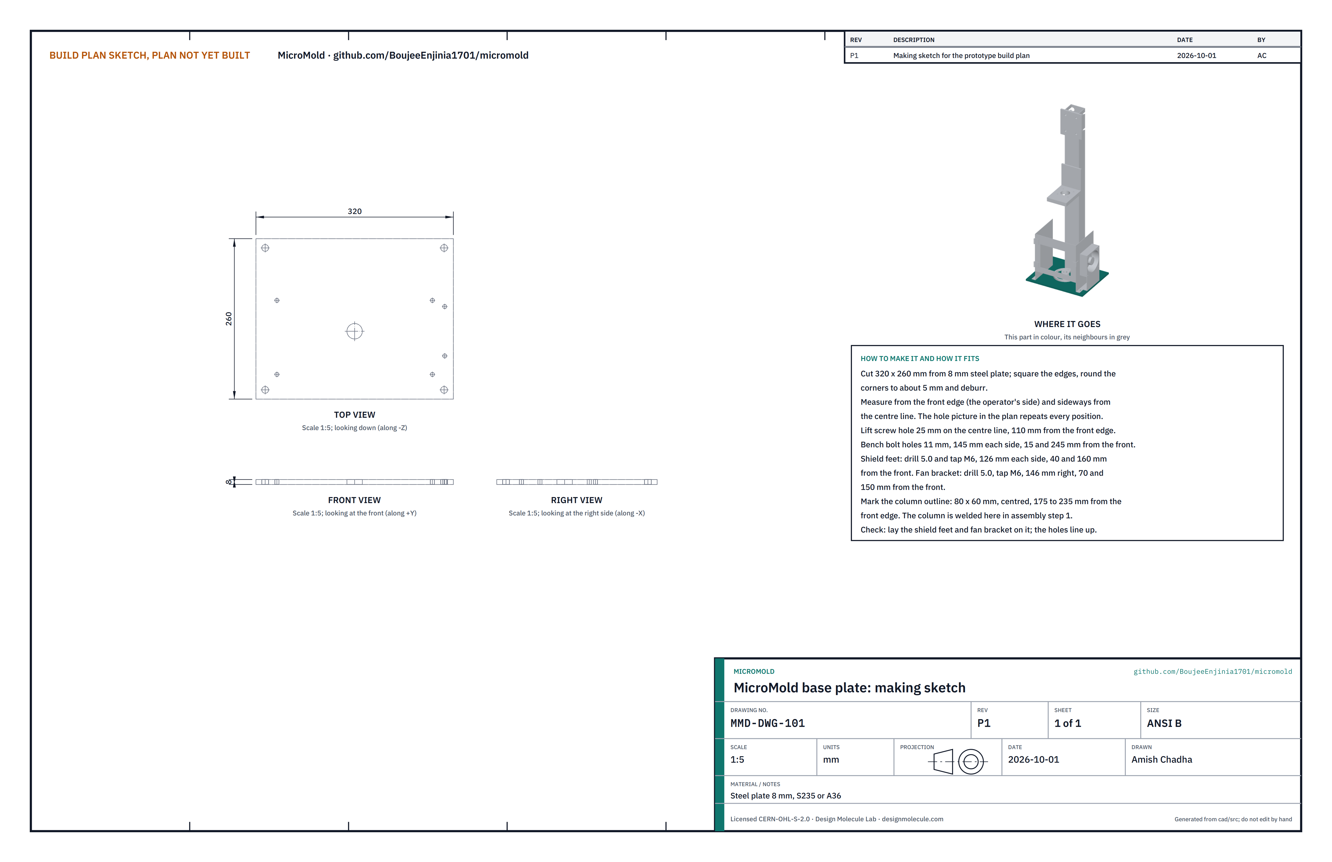
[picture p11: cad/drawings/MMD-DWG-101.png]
Figure 2. Making sketch of the base plate


*Figure 2. Base plate making sketch (MMD-DWG-101).*

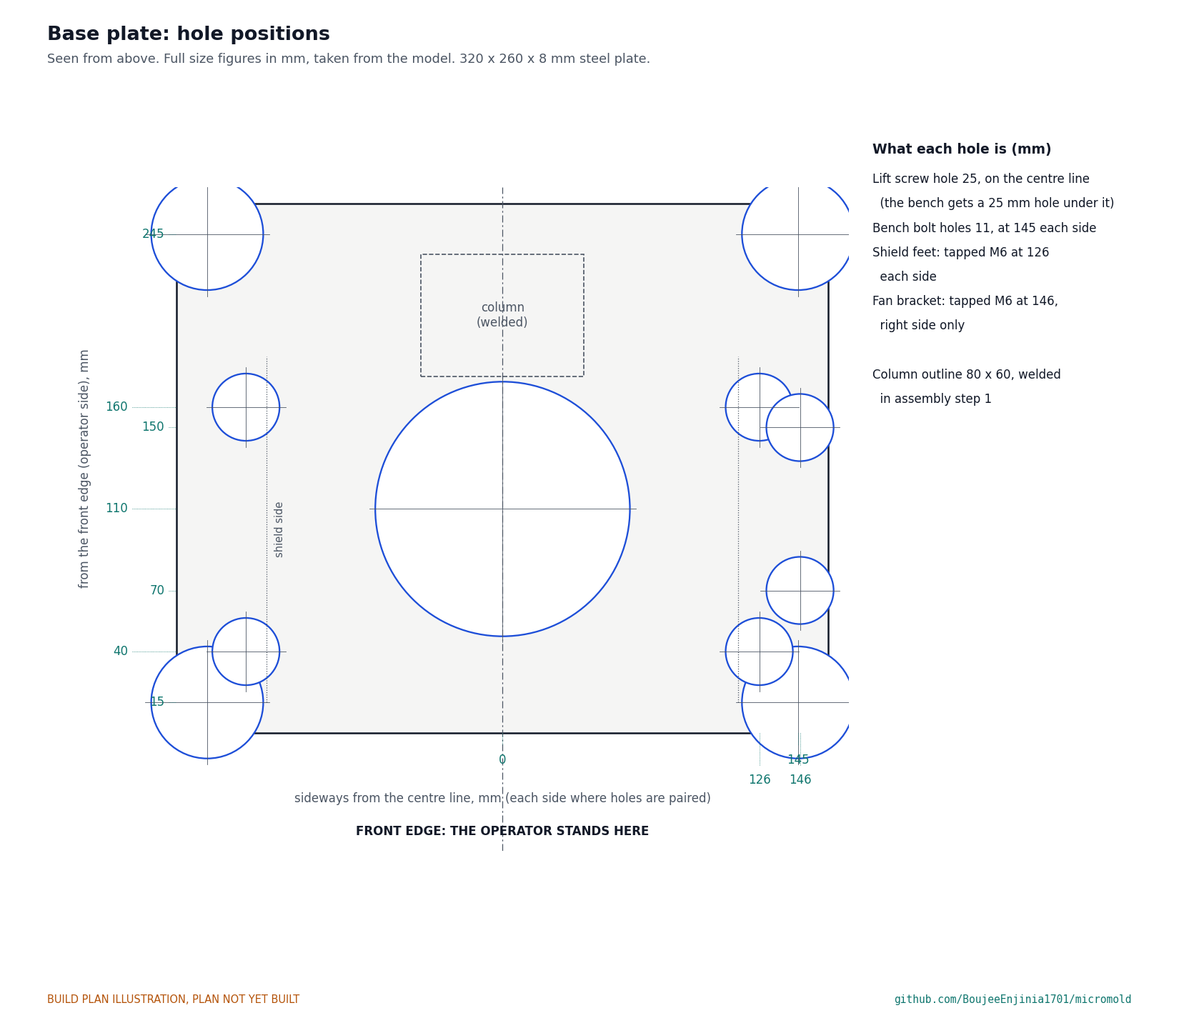
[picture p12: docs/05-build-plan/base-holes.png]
Figure 3. Hole positions in the base plate


*Figure 3. Every hole, full size figures, measured from the front edge and sideways from the centre line.*

**What it is and what it is made from.** The plate the whole press stands on, bolted to the bench. Steel plate 8 mm thick, S235 or A36, cut to 320 x 260 mm.

**How to make it.**

1. Cut the blank to 320 x 260 mm, square. Round the corners to about 5 mm and deburr all edges.
2. Scribe a centre line front to back. Mark the front edge (the operator's side).
3. Mark every hole from Figure 3: distances back from the front edge, sideways from the centre line.
4. Lift screw hole: 25 mm, on the centre line, 110 back from the front edge.
5. Bench bolt holes: four 11 mm holes, 145 each side, 15 and 245 back.
6. Shield foot holes: four holes 126 each side, 40 and 160 back. Drill 5.0 mm and tap M6.
7. Fan bracket holes: two holes 146 to the right, 70 and 150 back. Drill 5.0 mm and tap M6.
8. Scribe the column outline: 80 wide, centred, from 175 to 235 back.
9. Deburr every hole on both faces.

**How it fits the parts next to it.** The column is welded on its outline (step 1). The handwheel nut turns on a thrust washer over the lift screw hole (Figure 7). The shield feet and the fan bracket foot screw down onto it (Figures 21 and 23). Four M10 bolts hold it to the bench, over a 25 mm hole drilled through the bench under the lift screw hole.

**Check before moving on.** Lay the shield feet and fan bracket on the plate and look through each hole: the holes must line up without forcing a screw.

### 3.2 Column with shelf, back plate and head plate

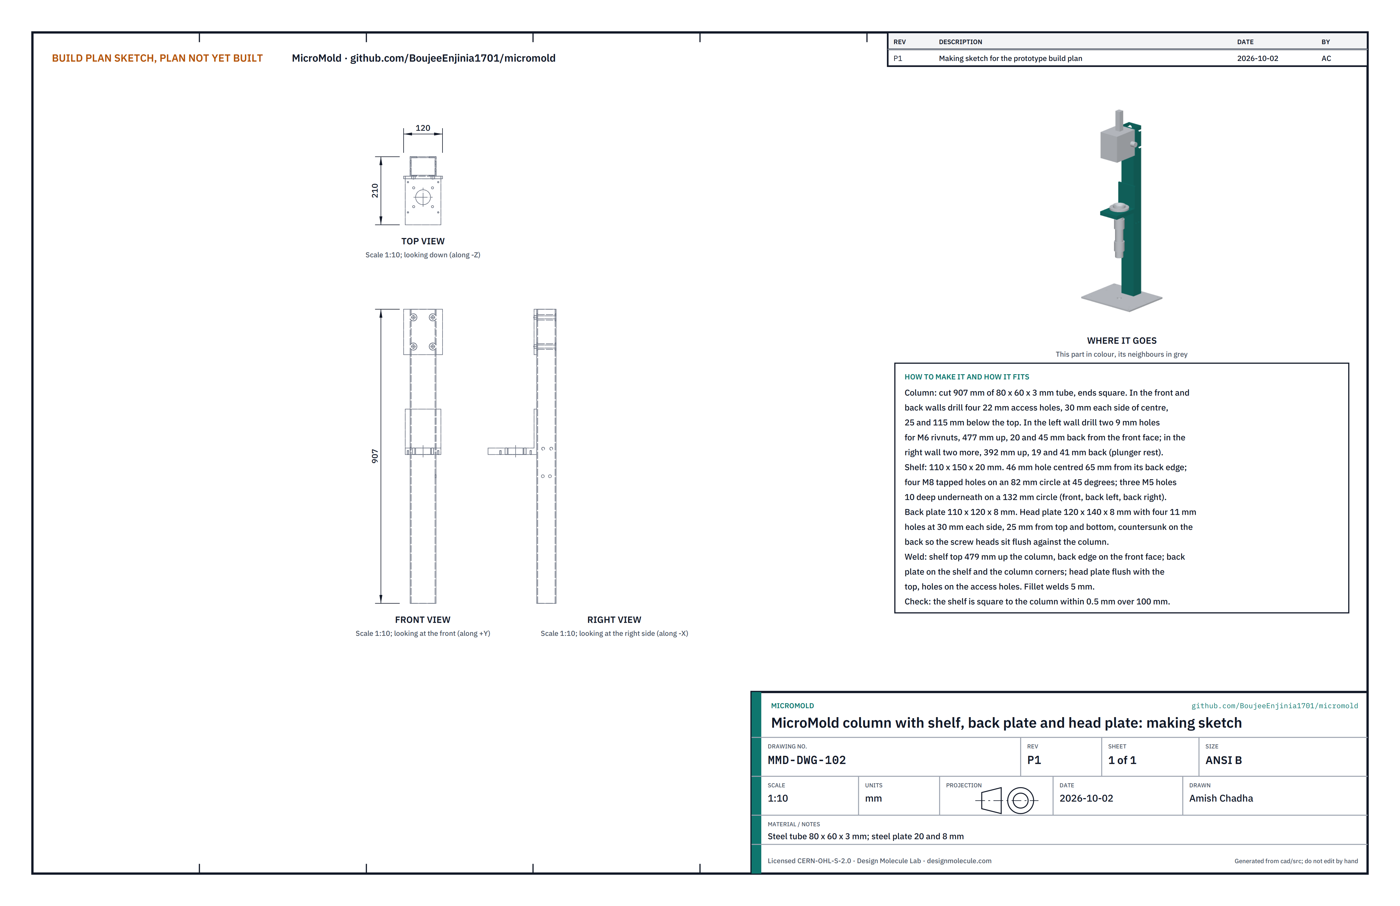
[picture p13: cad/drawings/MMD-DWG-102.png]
Figure 4. Making sketch of the column weldment


*Figure 4. Column weldment making sketch (MMD-DWG-102).*

**What it is and what it is made from.** The spine of the press: a steel tube that carries the press head at its top and the barrel on a shelf half way up, with the plates welded to it that hold them. Steel tube 80 x 60 x 3 mm; steel plate 20 mm (shelf) and 8 mm (back plate and head plate).

**How to make it.**

1. Column: cut 907 mm of tube with square ends. The 80 mm faces are the front and back.
2. In the front and back walls, drill four 22 mm access holes through both walls in line: 30 each side of the centre line, 25 and 115 below the top end.
3. In the left wall, drill two 9 mm holes for M6 rivnuts, 477 up from the bottom end, 20 and 45 back from the front face. In the right wall, drill two more, 392 up from the bottom end, 19 and 41 back from the front face. Fit all four rivnuts.
4. Shelf: cut 110 x 150 mm from 20 mm plate. Drill a 46 mm hole centred across the width, 65 from one short edge (the back edge). Around it, on an 82 mm circle, drill and tap four M8 holes through, at 45 degrees to the edges. Underneath, drill and tap four M5 holes 10 deep on a 132 mm circle round the same centre, at 45 degrees to the edges.
5. Back plate: cut 110 x 120 mm from 8 mm plate.
6. Head plate: cut 120 x 140 mm from 8 mm plate. Drill four 11 mm holes, 30 each side of centre, 25 from the top and bottom edges. Countersink them 90 degrees on one face (the back face) so an M10 countersunk screw sits flush.
7. Weld, in this order, with 5 mm fillet welds: the head plate to the column front, back face to the column, top edge flush with the column top, its holes in line with the access holes (weld down both column corners and across the top); the shelf with its back edge against the column front and its top face 479 up from the column bottom, centred, square both ways (weld top and bottom); the back plate on the shelf against the column (weld to the shelf and down both column corners).
8. Clean up spatter and paint everything except the shelf top.

**How it fits the parts next to it.** The column stands on the base plate, welded all round (step 1). The press head bolts to the head plate (Figure 9). The barrel flange sits on mica pads on the shelf (Figure 14), and the jacket hangs under it (Figure 16). The lift table's back edge runs 2 mm in front of the column face (Figure 6). The hood arm bolts to the left-hand rivnuts (Figure 25) and the plunger rest to the right-hand ones (Figure 29).

**Check before moving on.** The shelf is square to the column within 0.5 mm over 100 mm, both ways; an M10 screw passes through each access hole into each head plate hole.

### 3.3 Lift table and screw

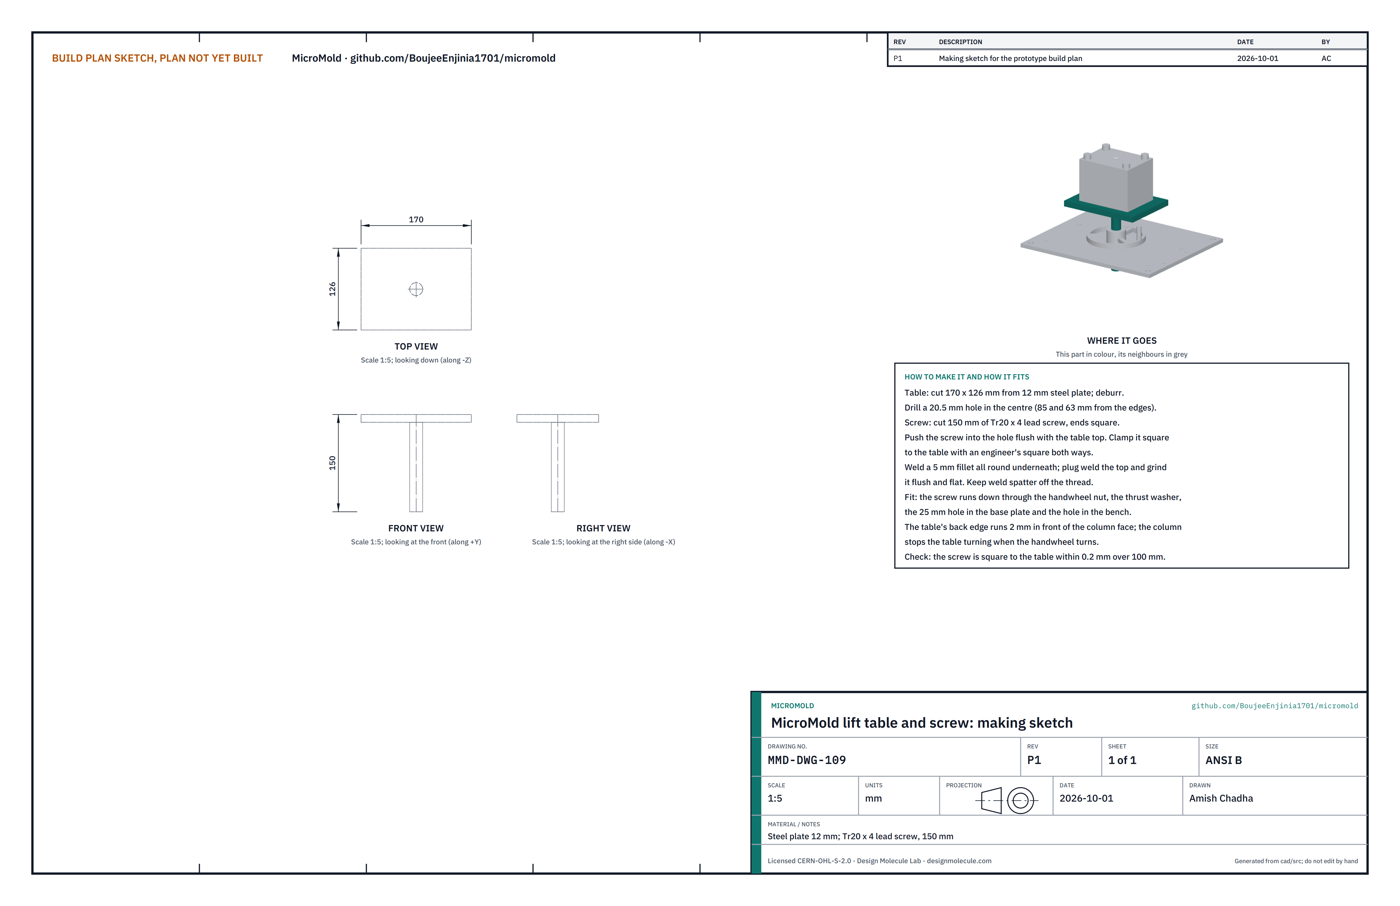
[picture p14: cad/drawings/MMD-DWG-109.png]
Figure 5. Making sketch of the lift table


*Figure 5. Lift table and screw making sketch (MMD-DWG-109).*

**What it is and what it is made from.** The table the mold stands on, with its lifting screw welded underneath. Steel plate 12 mm; Tr20 x 4 trapezoidal lead screw, 150 mm.

**How to make it.**

1. Cut the table 170 x 126 mm from 12 mm plate and deburr it.
2. Drill a 20.5 mm hole in the centre, 85 from the sides and 63 from the front and back edges.
3. Cut 150 mm of Tr20 x 4 screw with square ends.
4. Push the screw into the hole flush with the table top, and clamp it square to the table both ways with an engineer's square.
5. Weld a 5 mm fillet all round underneath. Plug weld the top and grind it flush and flat. Keep weld spatter off the thread.

**How it fits the parts next to it.**

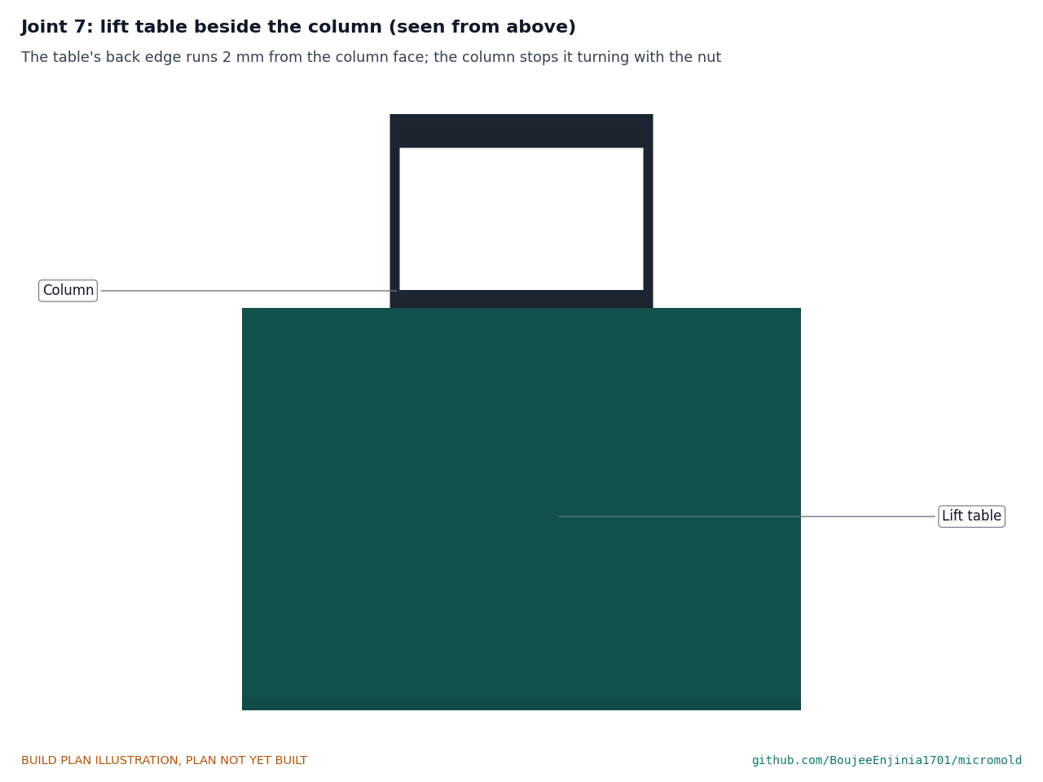
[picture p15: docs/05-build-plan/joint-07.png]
Figure 6. Joint 7: the lift table beside the column, seen from above


*Figure 6. The table's back edge runs 2 mm in front of the column face; when the handwheel turns, the column stops the table turning with it.*

The screw runs down through the handwheel nut, the thrust washer, the base plate and the bench (Figure 7). The mold stands on the table.

**Check before moving on.** The screw is square to the table within 0.2 mm over 100 mm.

### 3.4 Handwheel nut

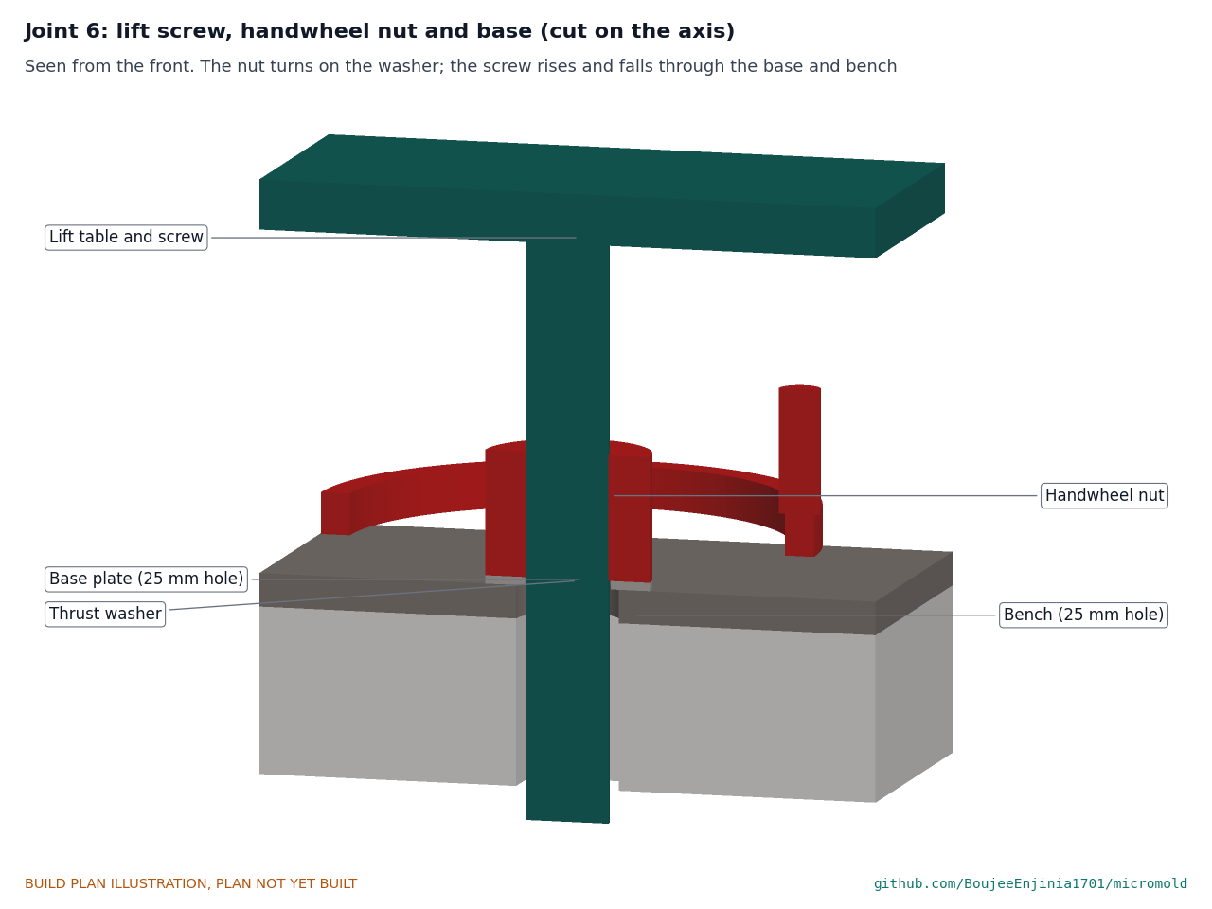
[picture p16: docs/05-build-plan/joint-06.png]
Figure 7. Joint 6: lift screw, handwheel nut and base, cut on the axis


*Figure 7. The nut turns on the thrust washer; the screw rises and falls through the base plate and the bench.*

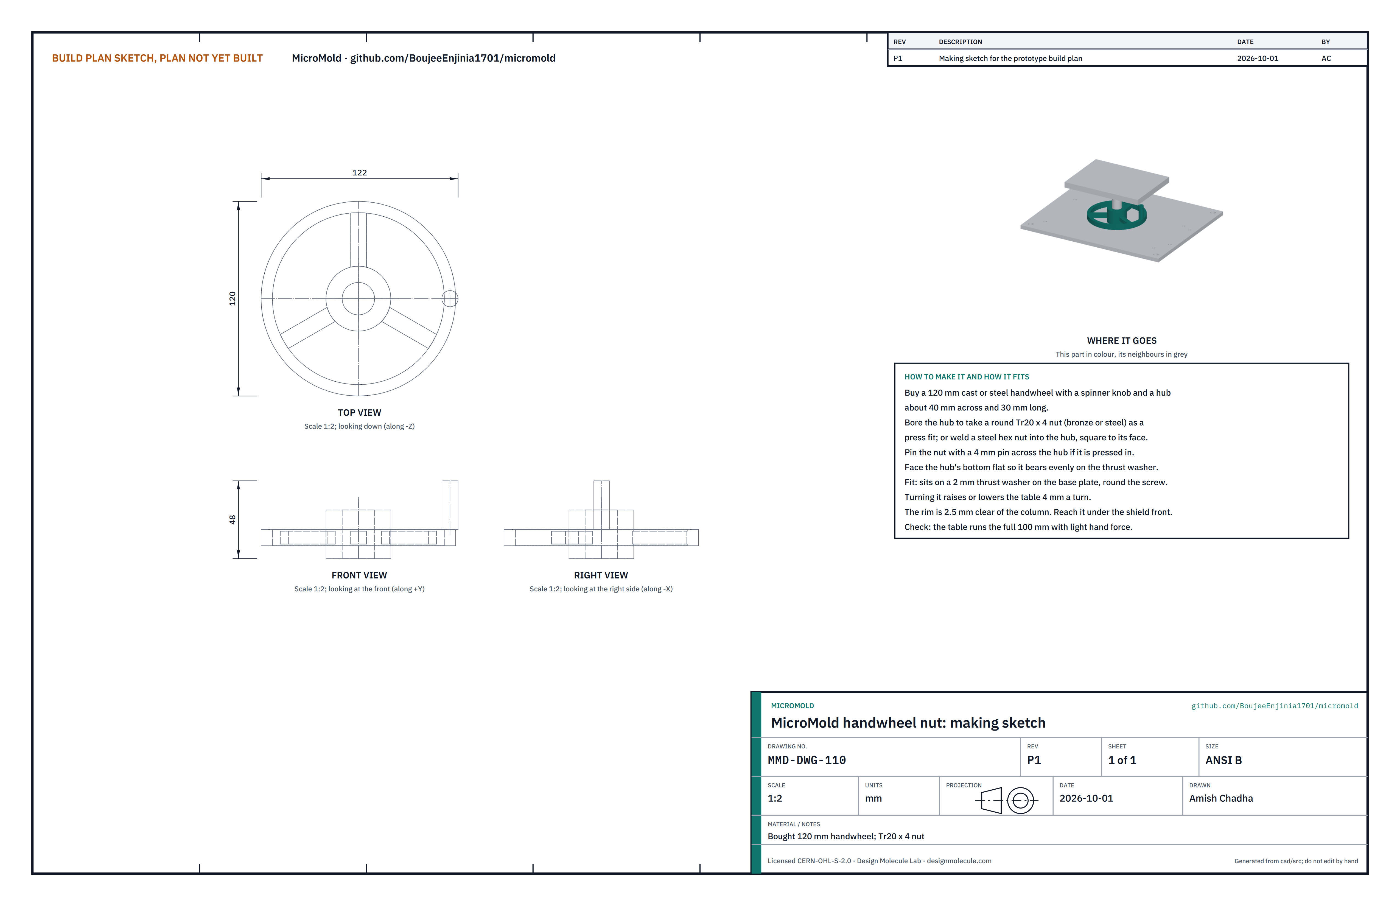
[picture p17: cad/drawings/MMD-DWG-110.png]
Figure 8. Making sketch of the handwheel nut


*Figure 8. Handwheel nut making sketch (MMD-DWG-110).*

**What it is and what it is made from.** The wheel that raises and lowers the table: a bought handwheel with a Tr20 x 4 nut fitted in its hub. A 120 mm cast or steel handwheel with a spinner knob and a hub about 40 mm across and 30 long; a round Tr20 x 4 nut in bronze or steel.

**How to make it.**

1. Bore the hub to take the nut as a press fit, or weld a steel nut into the hub square to its face.
2. If pressed in, pin the nut with a 4 mm pin across the hub.
3. Face the hub's bottom flat so it bears evenly on the thrust washer.

**How it fits the parts next to it.** The hub sits on a 2 mm thrust washer on the base plate, round the screw. One turn moves the table 4 mm; the table runs from 60 to 160 above the bench. The rim runs 2.5 mm clear of the column and is reached under the shield's front edge, which is 60 above the bench, with the front shut. With the table at its lowest, the screw end is 50 mm below the underside of a 40 mm bench.

**Check before moving on.** On a trial fit the table runs its full 100 mm with light hand force.

### 3.5 Arbor press head (bought, cut from its frame)

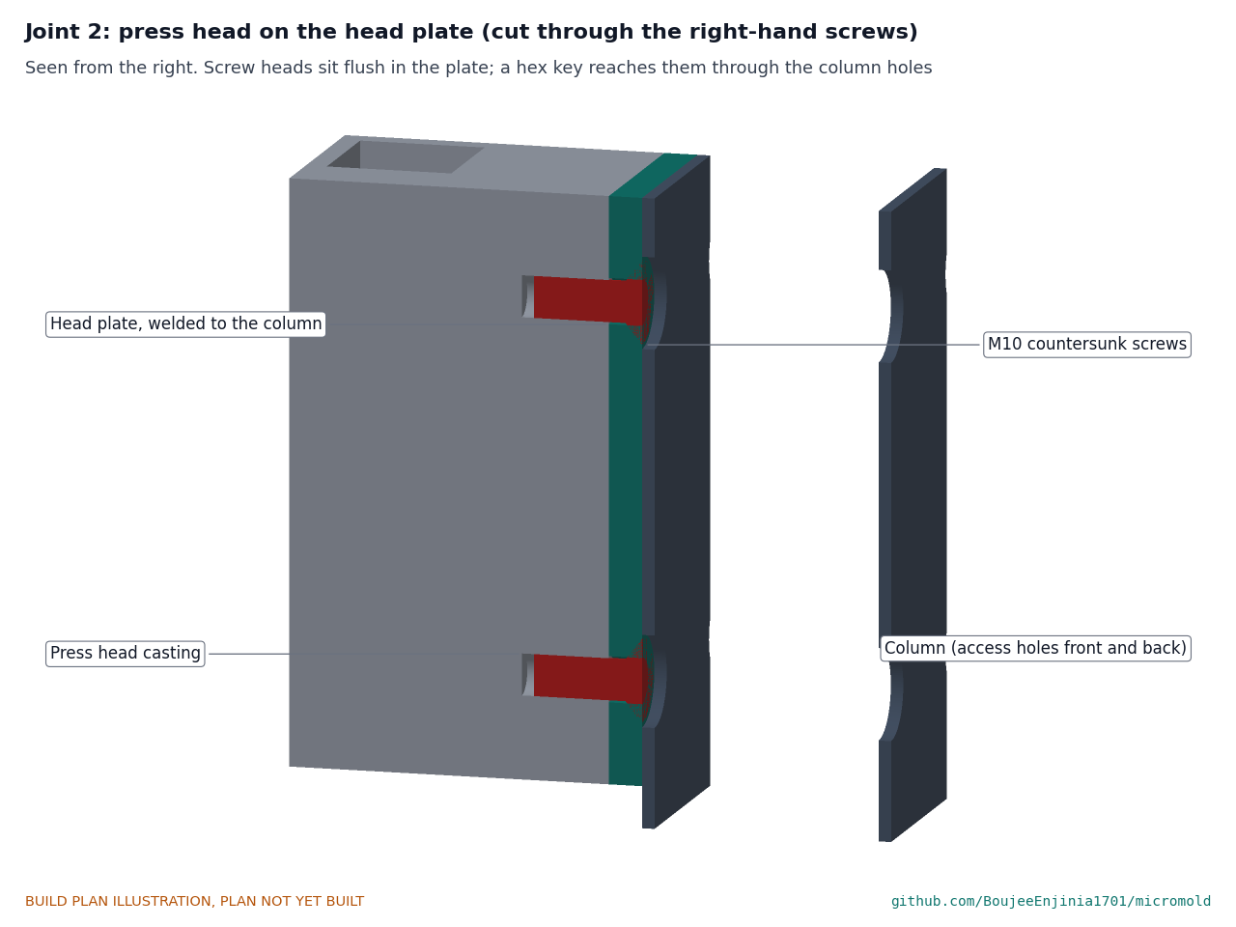
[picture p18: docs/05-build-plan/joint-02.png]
Figure 9. Joint 2: press head on the head plate, cut through the right-hand screws


*Figure 9. The countersunk screw heads sit flush in the head plate; a hex key reaches them through the holes in the column.*

**What it is and what it is made from.** The rack, pinion and head casting of a 1 t arbor press. The ram must be 28 mm square and 255 mm or longer, with 150 mm of travel while the rack still meets the pinion.

**How to make it.**

1. Take the lever and its hub off the pinion shaft; keep the hub for the ratchet adapter (section 3.6).
2. Cut the head from the press frame just below the head casting with a cutting disc, and grind the back face flat where it will meet the head plate.
3. Using the head plate as a template, mark four holes on the back face (60 apart across, 90 apart up and down, centred on the ram's centre line across). Drill 8.5 mm and tap M10, 20 deep.
4. Do this before step 2, the cut: check the bought head against what the plan assumes: at least 8 mm of casting between each M10 hole and the ram bore, room for a 20 mm thread behind each hole, and a flat back face about 140 mm deep. If the head differs, stop and send the measurements to the designer so the drawings are revised before any cut is made.

**How it fits the parts next to it.** The back face sits flat on the head plate. Four M10 x 25 countersunk screws go in from behind the head plate, through the column's access holes, with medium threadlocker. The ram's centre is 65 in front of the column face, over the barrel bore.

**Check before moving on.** The ram slides its full travel without binding, and its end face is square to the base plate within 0.5 mm over its width (checked at step 6).

### 3.6 Ratchet adapter and torque-limiting socket

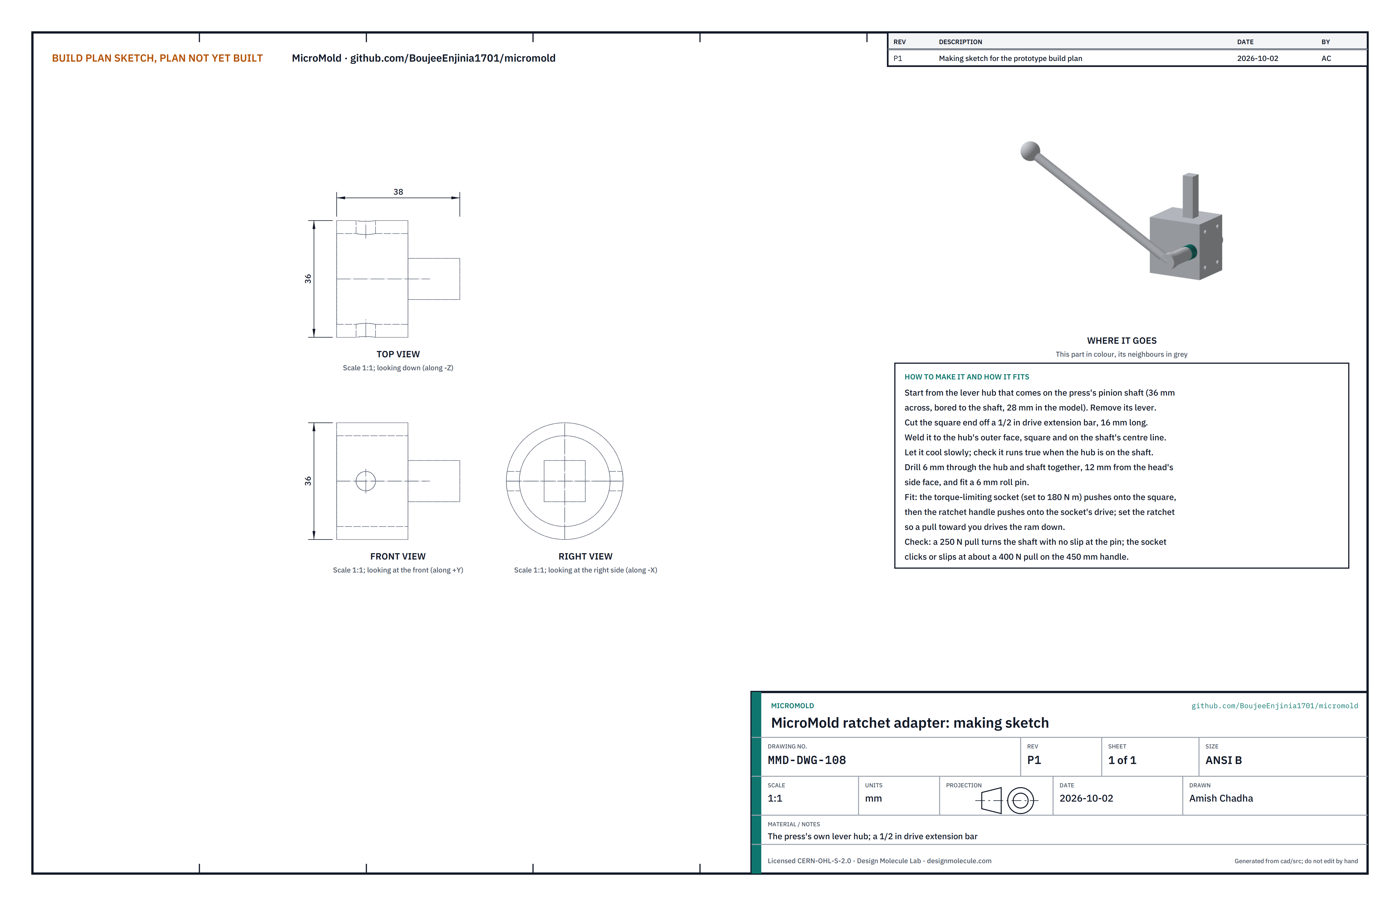
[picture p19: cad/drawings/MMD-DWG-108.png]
Figure 10. Making sketch of the ratchet adapter


*Figure 10. Ratchet adapter making sketch (MMD-DWG-108).*

**What it is and what it is made from.** The piece that lets a 1/2 in drive ratchet handle turn the pinion, and the socket that keeps the pull within the press rating. The adapter is the press's own lever hub (about 36 mm across, bored to the shaft) and the square end of a 1/2 in drive extension bar. The torque-limiting socket is a bought 1/2 in drive socket that slips at a set torque, rated for at least 200 N·m.

**How to make it.**

1. Cut the square end off a 1/2 in drive extension bar, 16 long.
2. Weld it to the hub's outer face, square to the face and on the shaft's centre line. Let it cool slowly; check it runs true with the hub on the shaft.
3. With the hub on the shaft, drill 6 mm through hub and shaft together, 12 from the head's side face, and fit a 6 mm roll pin.

**How it fits the parts next to it.** The hub slides onto the right-hand end of the pinion shaft, pinned. The torque-limiting socket pushes onto the square and the ratchet handle's square drive pushes onto the socket; the 450 mm handle starts a pull 30 degrees above level. Set the socket to 180 N·m (accurate to about 10 per cent). A 1 t press is at its rating at about 234 N·m, so even the worst setting of 198 N·m leaves the ram at 0.85 times the rating. The socket slips at a pull of about 400 N on the handle, well above the 250 N working pull, and a person hanging their weight on the handle cannot overload the press.

**Check before moving on.** A 250 N pull at the handle turns the shaft with no movement at the pin and no slip at the socket.

### 3.7 Nozzle

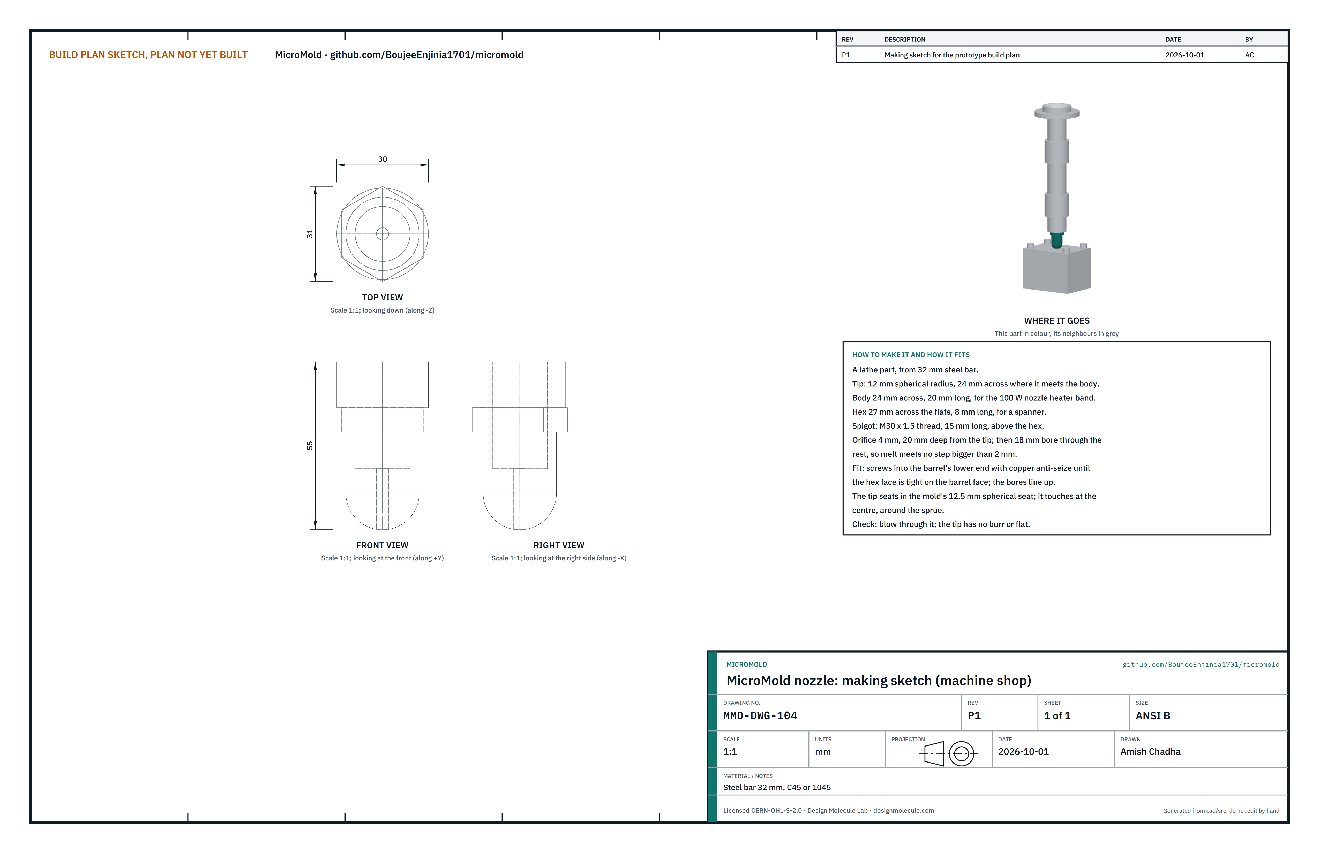
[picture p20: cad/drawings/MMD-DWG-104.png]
Figure 11. Making sketch of the nozzle


*Figure 11. Nozzle making sketch (MMD-DWG-104).*

**What it is and what it is made from.** The short heated tip that melt leaves through into the mold. Turned from 32 mm steel bar, C45 or 1045, by a machine shop.

**How to make it.**

1. Turn the tip to a 12 mm spherical radius, 24 across where it meets the body.
2. Turn the body to 24 across and 20 long, for the 100 W nozzle heater band.
3. Leave a hex 27 across the flats and 8 long above the body.
4. Turn and thread the spigot above the hex: M30 x 1.5, 15 long.
5. Drill the orifice 4 mm, 20 deep from the tip, then 18 mm through the rest, so melt meets no step bigger than 2 mm.

**How it fits the parts next to it.** The spigot screws into the barrel's lower end with copper anti-seize until the hex face is tight on the barrel face. The heater band clamps round the body. The tip sits in the mold's spherical seat, touching round the sprue (Figure 13).

**Check before moving on.** Blow through it; the tip has no burr or flat.

### 3.8 Barrel

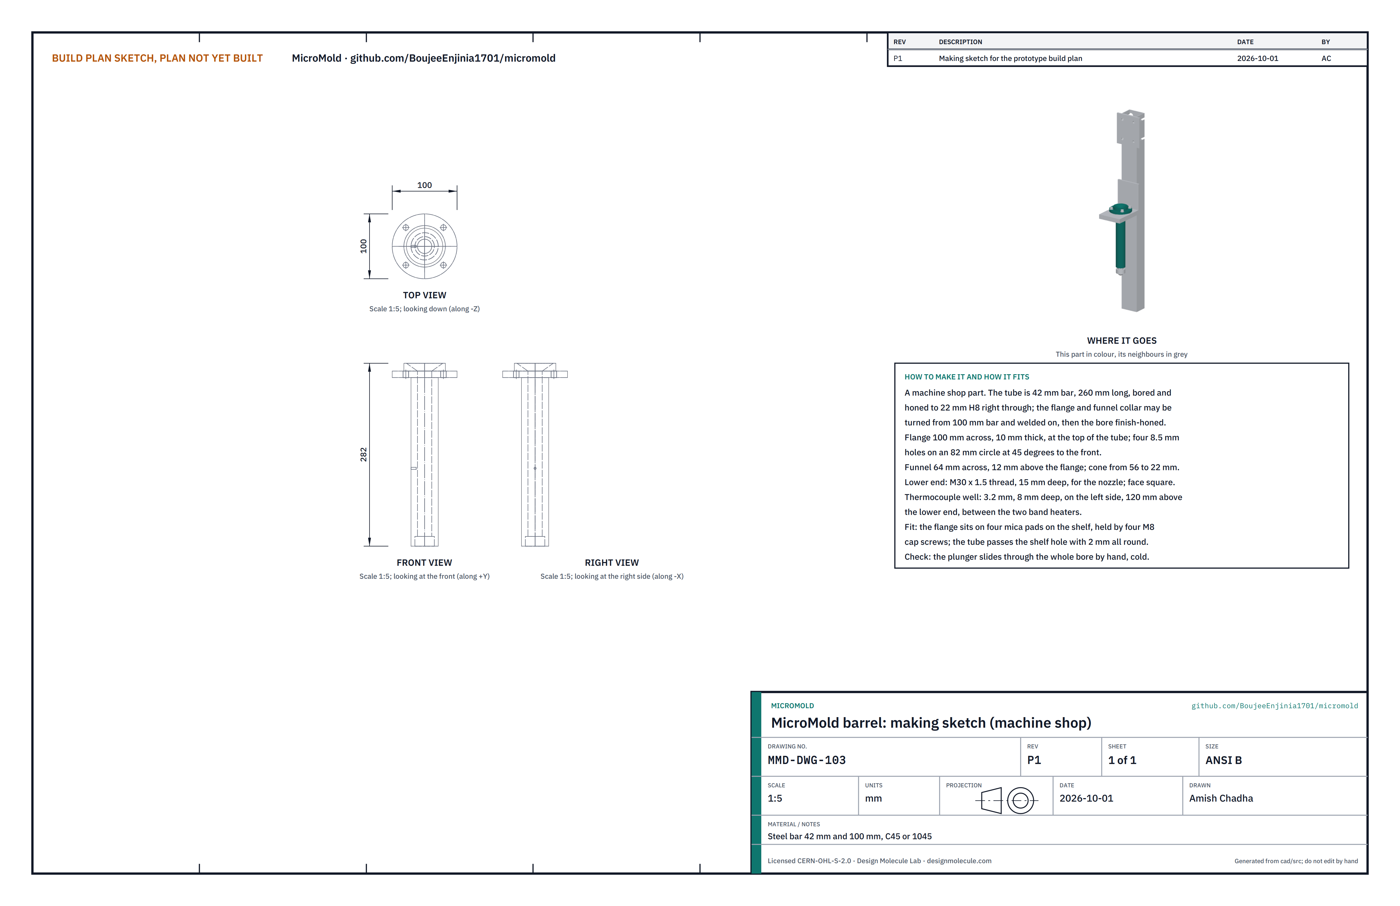
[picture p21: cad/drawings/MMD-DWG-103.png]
Figure 12. Making sketch of the barrel


*Figure 12. Barrel making sketch (MMD-DWG-103).*

**What it is and what it is made from.** The heated steel tube the plastic melts in, with a flange that sits on the shelf and a funnel for loading. Steel bar 42 mm and 100 mm, C45 or 1045, by a machine shop.

**How to make it.**

1. Bore and hone 42 mm bar, 260 long, to 22 mm H8 right through.
2. Turn the flange (100 across, 10 thick) and the funnel collar (64 across, 12 above the flange, a cone from 56 to 22) from 100 mm bar, weld them to the top of the tube, then finish-hone the bore. A shop may instead turn the whole barrel from 100 mm bar.
3. Drill four 8.5 mm holes in the flange on an 82 mm circle, at 45 degrees to the front.
4. Thread the lower end M30 x 1.5, 15 deep, face square.
5. Drill a 3.2 mm thermocouple well 8 deep in the left side, 120 above the lower end, between the two heater bands.

**How it fits the parts next to it.**

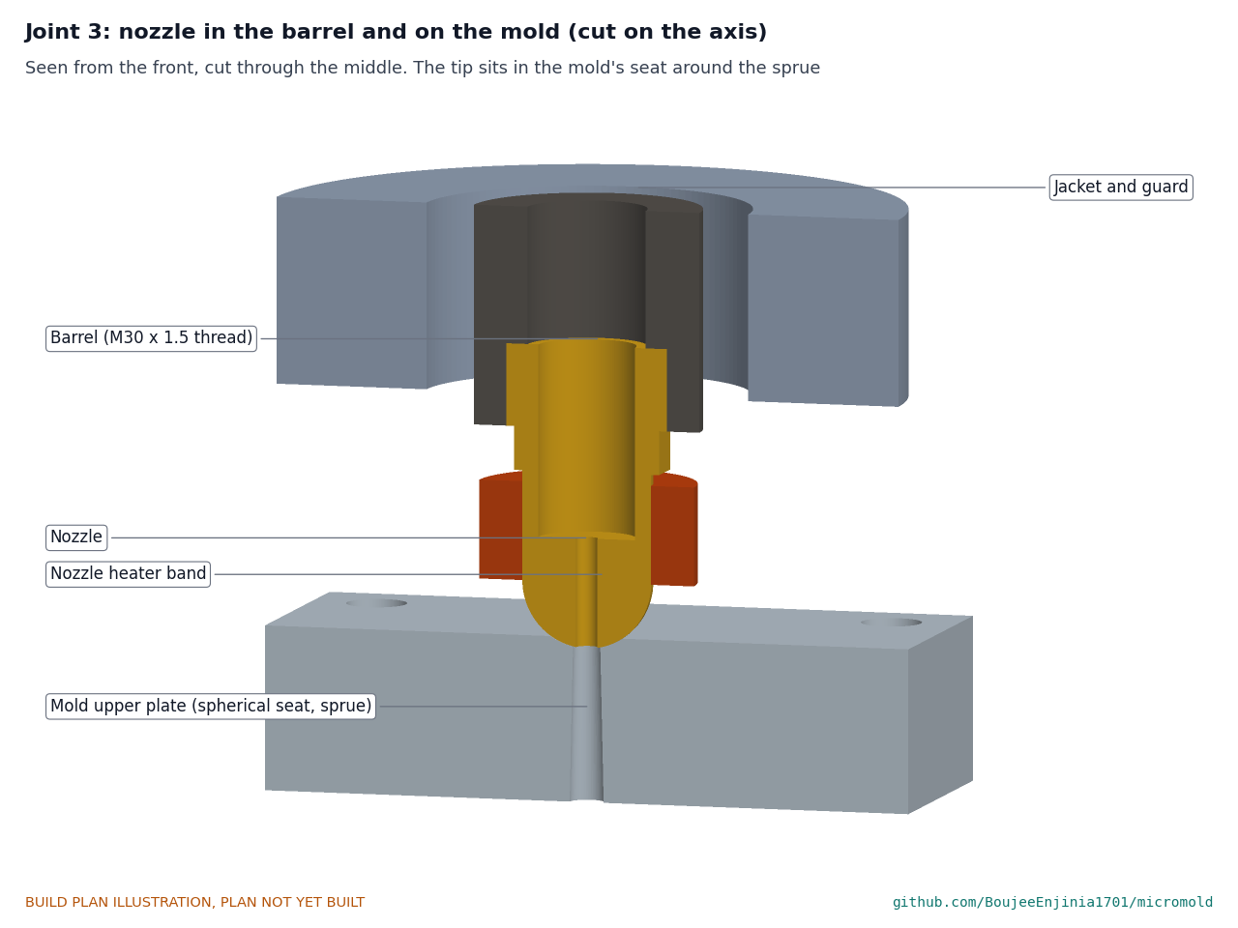
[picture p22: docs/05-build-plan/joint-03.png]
Figure 13. Joint 3: nozzle in the barrel and on the mold, cut on the axis


*Figure 13. The nozzle screws into the barrel's lower end; its tip sits in the mold's spherical seat round the sprue.*

The two 300 W band heaters clamp round the tube, centred 60 and 180 above its lower end, with their leads to the back. The tube passes down through the shelf's 46 mm hole with 2 mm all round, and the flange sits on four mica pads:

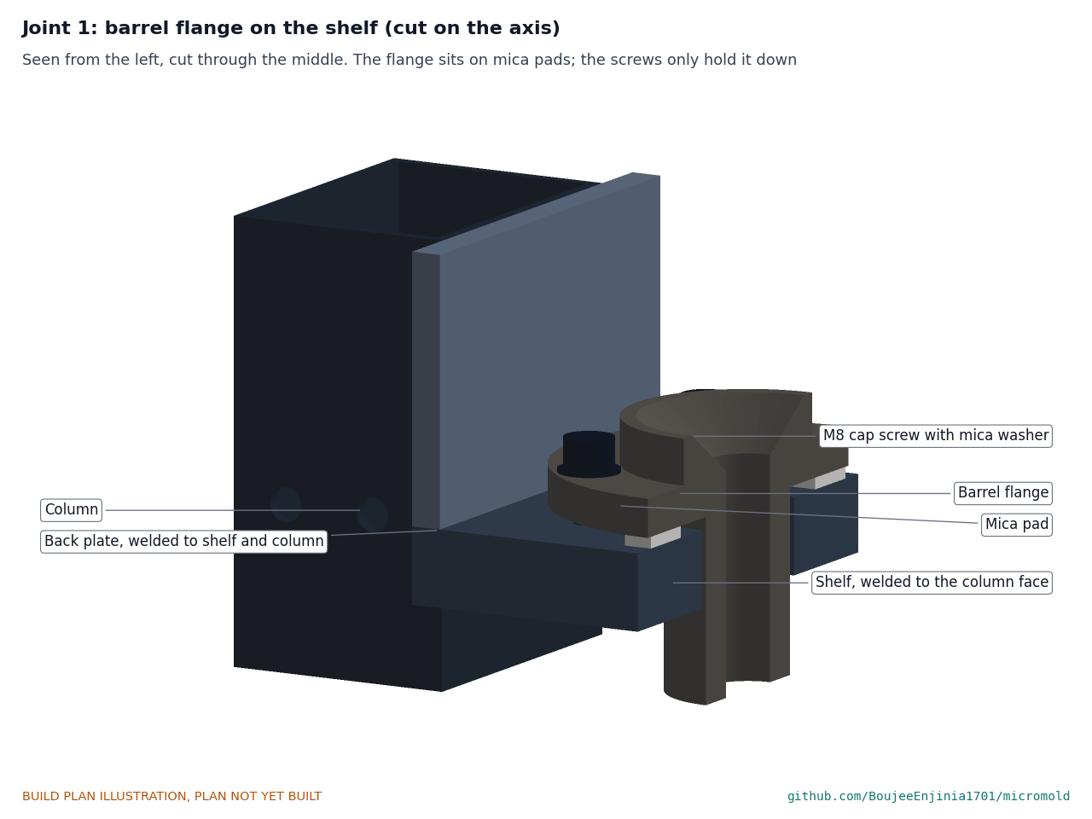
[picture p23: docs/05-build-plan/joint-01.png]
Figure 14. Joint 1: barrel flange on the shelf, cut on the axis


*Figure 14. Joint 1: the flange sits on four 15 x 15 x 3 mm mica pads on the shelf; four M8 cap screws with mica washers hold it down but carry no injection load.*

**Check before moving on.** The plunger slides through the whole bore by hand, cold; the nozzle bore lines up with the barrel bore.

### 3.9 Jacket and guard

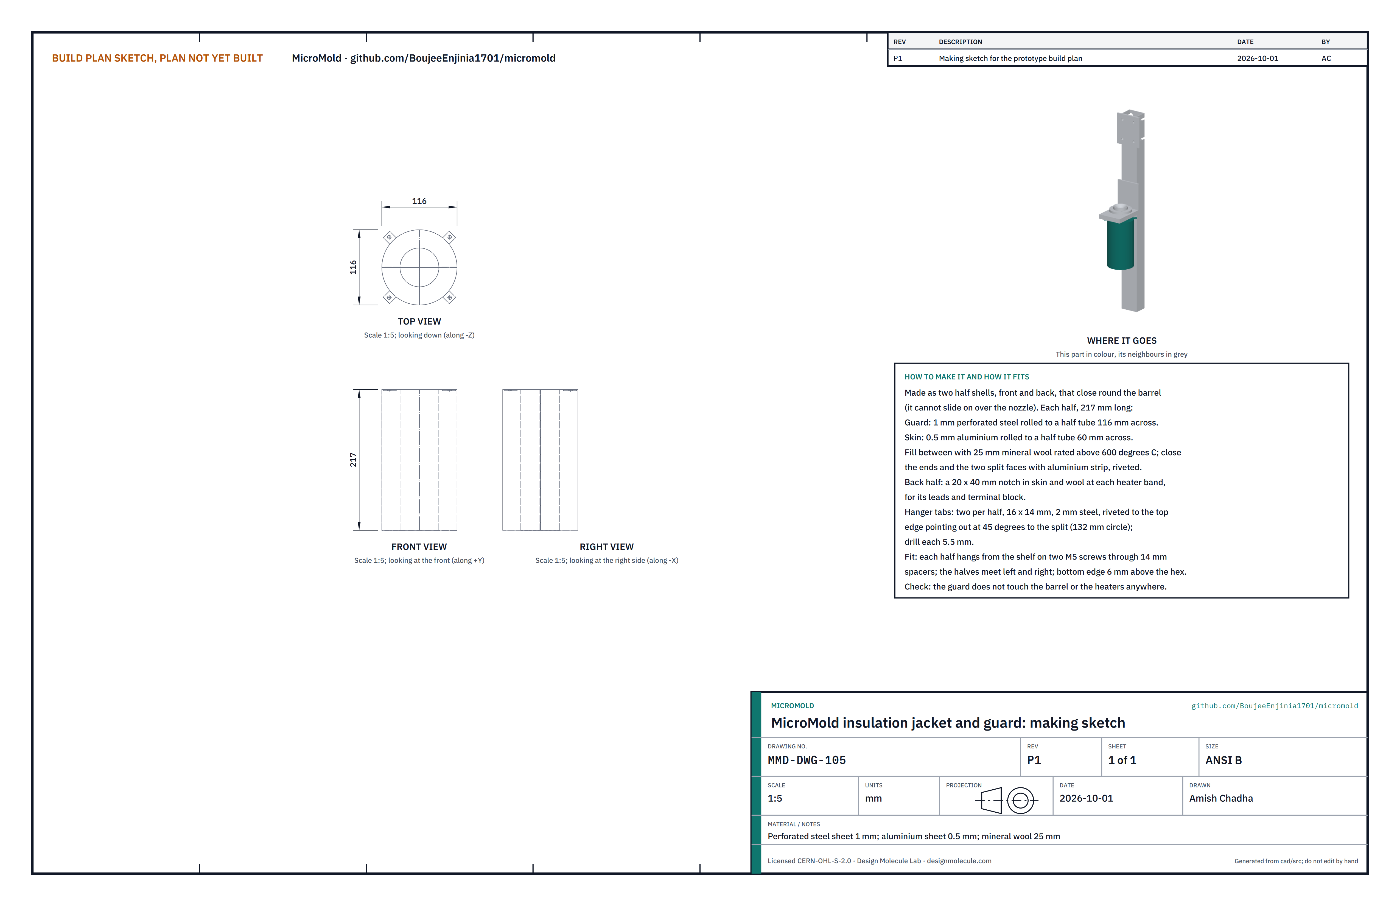
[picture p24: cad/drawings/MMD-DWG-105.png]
Figure 15. Making sketch of the jacket and guard


*Figure 15. Jacket and guard making sketch (MMD-DWG-105).*

**What it is and what it is made from.** The insulated sleeve round the heated barrel that keeps its outside near 48 °C, made as two half shells (front and back) because a one-piece sleeve cannot pass the nozzle once the barrel is in. Perforated steel sheet 1 mm (outside), aluminium sheet 0.5 mm (inside skin) and 25 mm mineral wool between them.

**How to make it.** Make each half 217 long:

1. Roll the perforated steel to a half tube 116 across.
2. Roll the aluminium skin to a half tube 60 across.
3. Fill between them with mineral wool rated above 600 °C and close the two ends and the two split faces with aluminium strip, riveted to the guard.
4. In the back half, cut a 20 x 40 mm notch in the skin and wool at each heater band, for its leads.
5. Rivet two 16 x 14 mm tabs of 2 mm steel to the top edge of each half, pointing out at 45 degrees to the split (on the same 132 mm circle as the shelf's M5 holes). Drill each tab 5.5 mm.

**How it fits the parts next to it.**

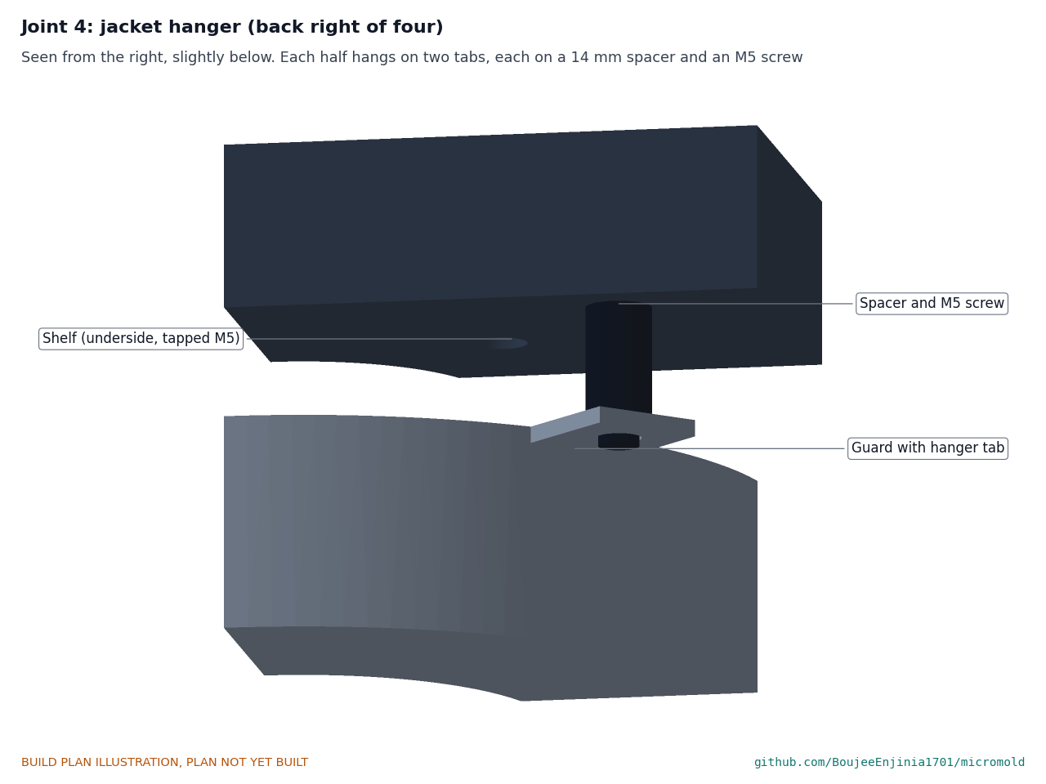
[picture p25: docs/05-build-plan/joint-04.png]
Figure 16. Joint 4: a jacket hanger, seen from below


*Figure 16. Each half hangs on two tabs, each on a 14 mm spacer and an M5 x 25 screw into the shelf.*

The halves meet at the left and right; the bottom edge sits 6 above the nozzle hex, and the guard is clear of the barrel and heaters all round.

**Check before moving on.** Nothing inside touches the barrel or the heaters.

### 3.10 Plunger coupling and thermal spacer

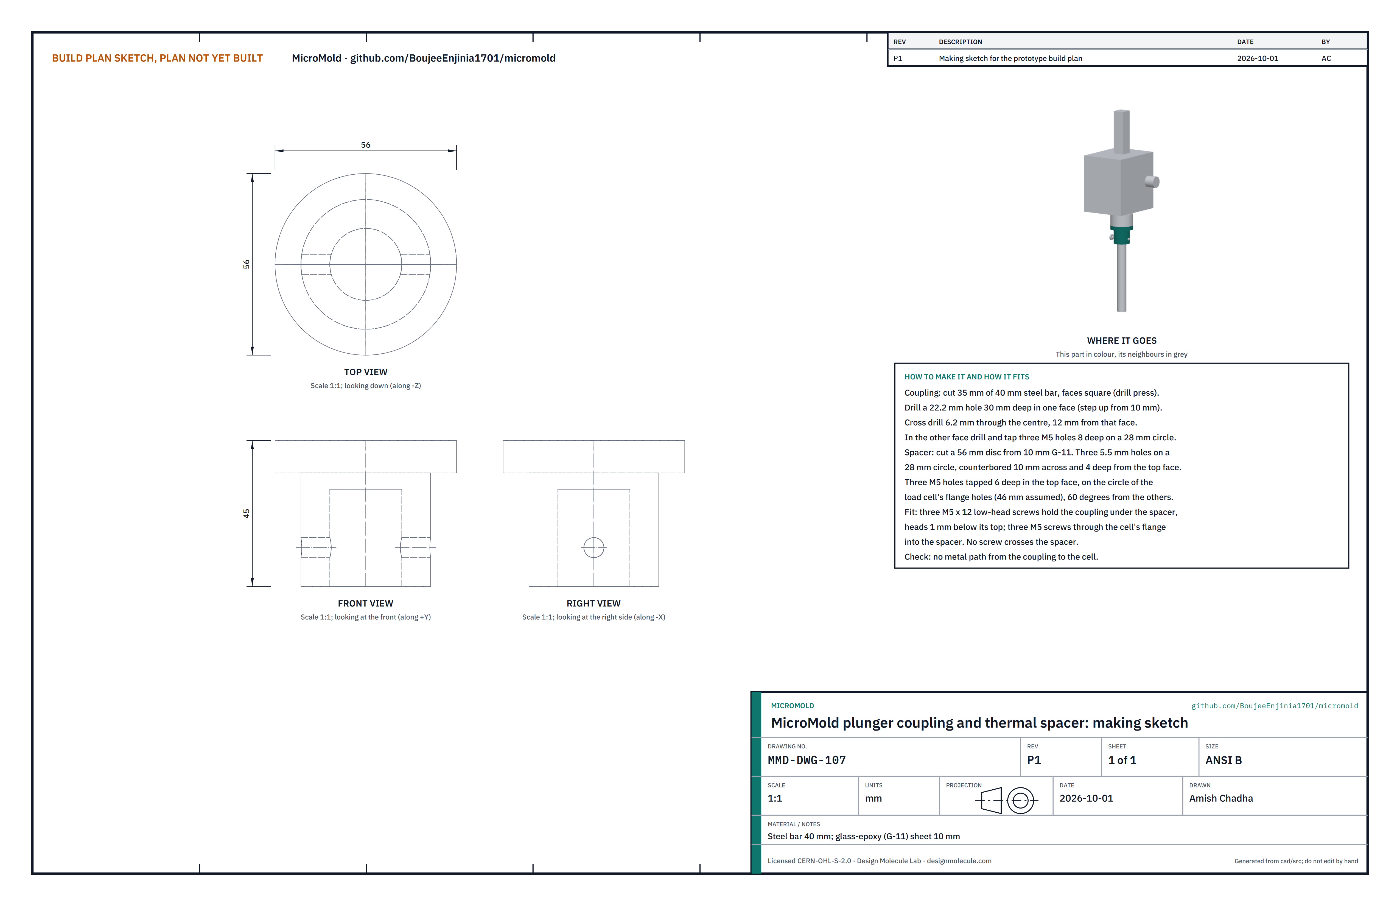
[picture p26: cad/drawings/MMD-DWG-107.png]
Figure 17. Making sketch of the coupling and spacer


*Figure 17. Plunger coupling and thermal spacer making sketch (MMD-DWG-107).*

**What they are and what they are made from.** The coupling holds the plunger under the load cell; the spacer stops the hot plunger heating the load cell. Steel bar 40 mm; glass-epoxy (G-11) sheet 10 mm.

**How to make them.**

1. Coupling: cut 35 mm of 40 mm bar with square faces. In one face drill a 22.2 mm hole 30 deep (step up from 10 mm on a drill press). Cross drill 6.2 mm through the centre, 12 from that face.
2. In the other face, drill and tap three M5 holes 8 deep on a 28 mm circle, 120 degrees apart.
3. Spacer: cut a 56 mm disc from 10 mm G-11. Drill three 5.5 mm holes on a 28 mm circle and counterbore them 10 across and 4 deep from the top face.
4. In the spacer's top face, drill and tap three M5 holes 6 deep on the circle of the load cell's flange holes (46 mm assumed), turned 60 degrees from the first three.

**How they fit the parts next to them.**

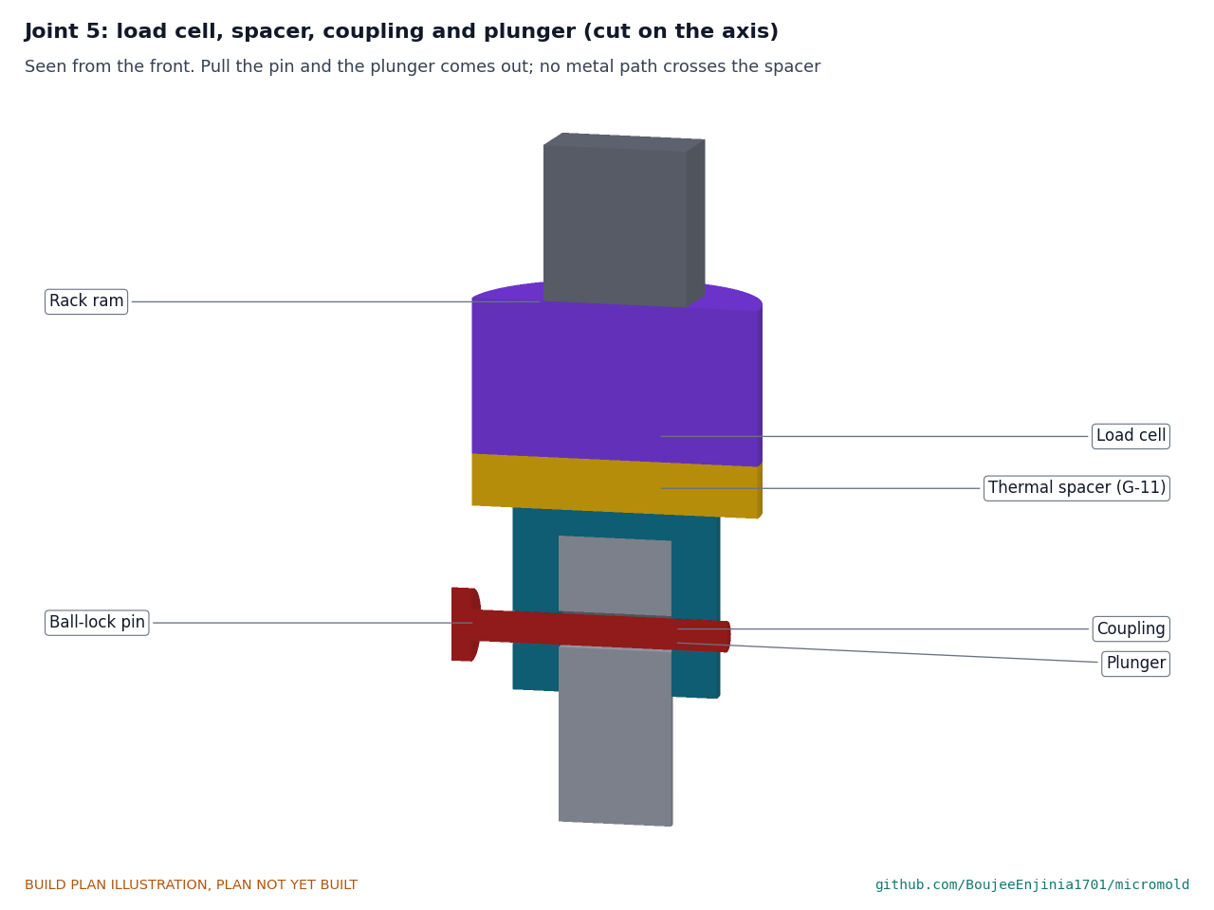
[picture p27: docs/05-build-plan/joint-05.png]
Figure 18. Joint 5: load cell, spacer, coupling and plunger, cut on the axis


*Figure 18. The load cell's stud screws into the ram end; the spacer and coupling hang under it; the plunger hangs on a ball-lock pin.*

Three M5 x 12 low-head screws go down through the spacer's counterbores into the coupling; their heads sit 1 mm below the spacer's top face. Three M5 screws go down through the load cell's flange into the spacer's tapped holes and stop 4 mm short of the coupling. No screw crosses the spacer, so no metal path carries heat to the load cell. Drill and tap the ram end M12, 20 deep, on its centre, for the load cell's stud. The plunger's top 30 mm goes into the coupling and a 6 mm ball-lock pin goes through both; the plunger's 7 mm hole lets it float in line with the bore.

**Check before moving on.** With a meter, there is no electrical path from the coupling to the load cell.

### 3.11 Plunger

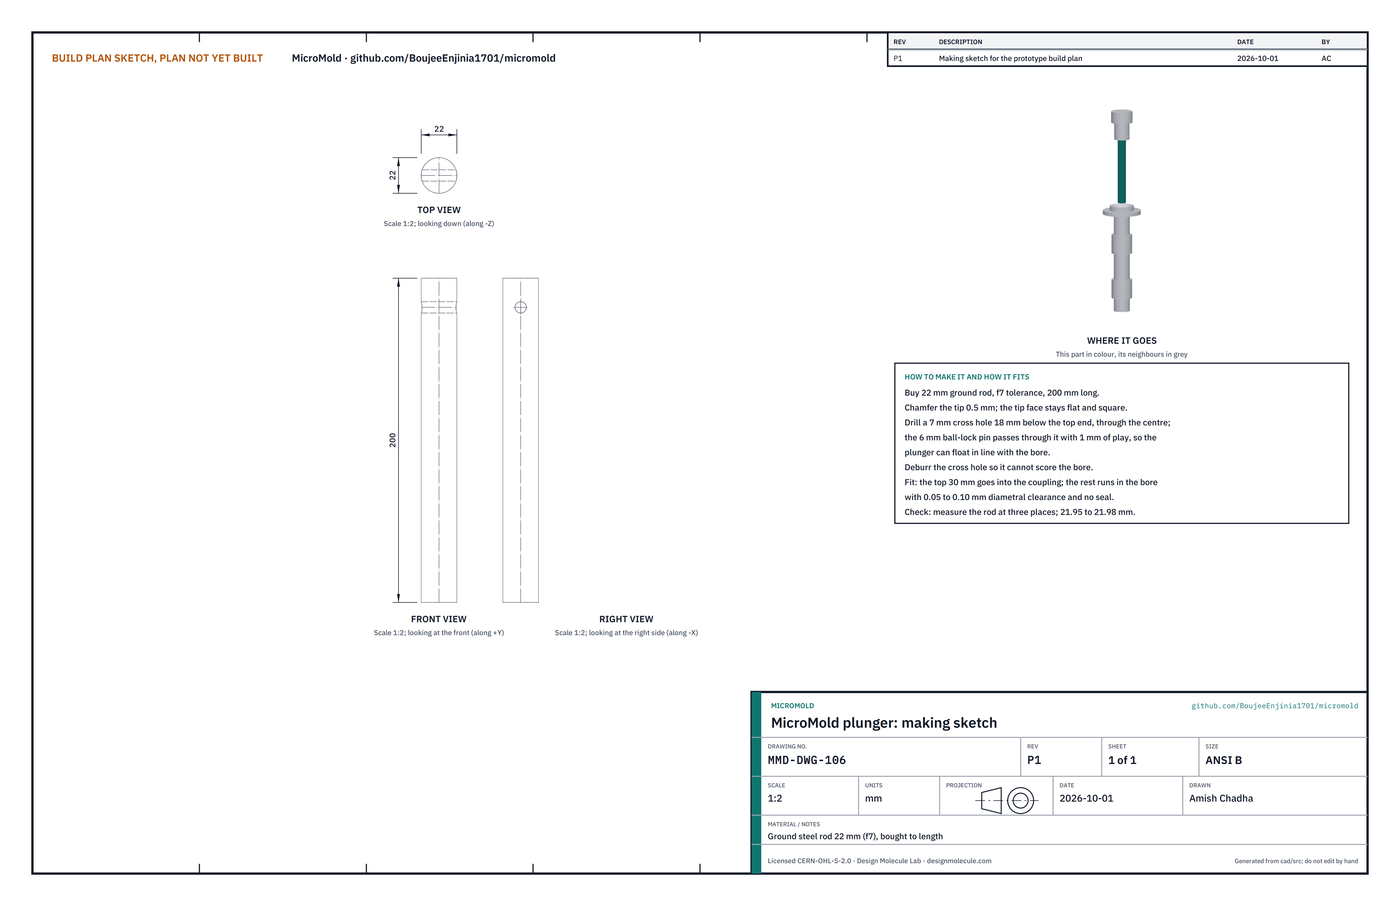
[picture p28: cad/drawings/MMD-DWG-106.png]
Figure 19. Making sketch of the plunger


*Figure 19. Plunger making sketch (MMD-DWG-106).*

**What it is and what it is made from.** The rod that pushes melt out of the barrel. Ground steel rod 22 mm, f7 tolerance, bought 200 mm long.

**How to make it.**

1. Chamfer the tip 0.5 mm; keep the tip face flat and square.
2. Drill a 7 mm cross hole through the centre, 18 below the top end, and deburr it so it cannot score the bore.

**How it fits the parts next to it.** It hangs in the coupling on the ball-lock pin (Figure 18) and runs in the bore with 0.05 to 0.10 mm diametral clearance and no seal. Raised, its tip is 30 above the barrel top; at full stroke it is 120 down the bore.

**Check before moving on.** Measure the rod at three places: 21.95 to 21.98 mm.

### 3.12 Nozzle zone shield

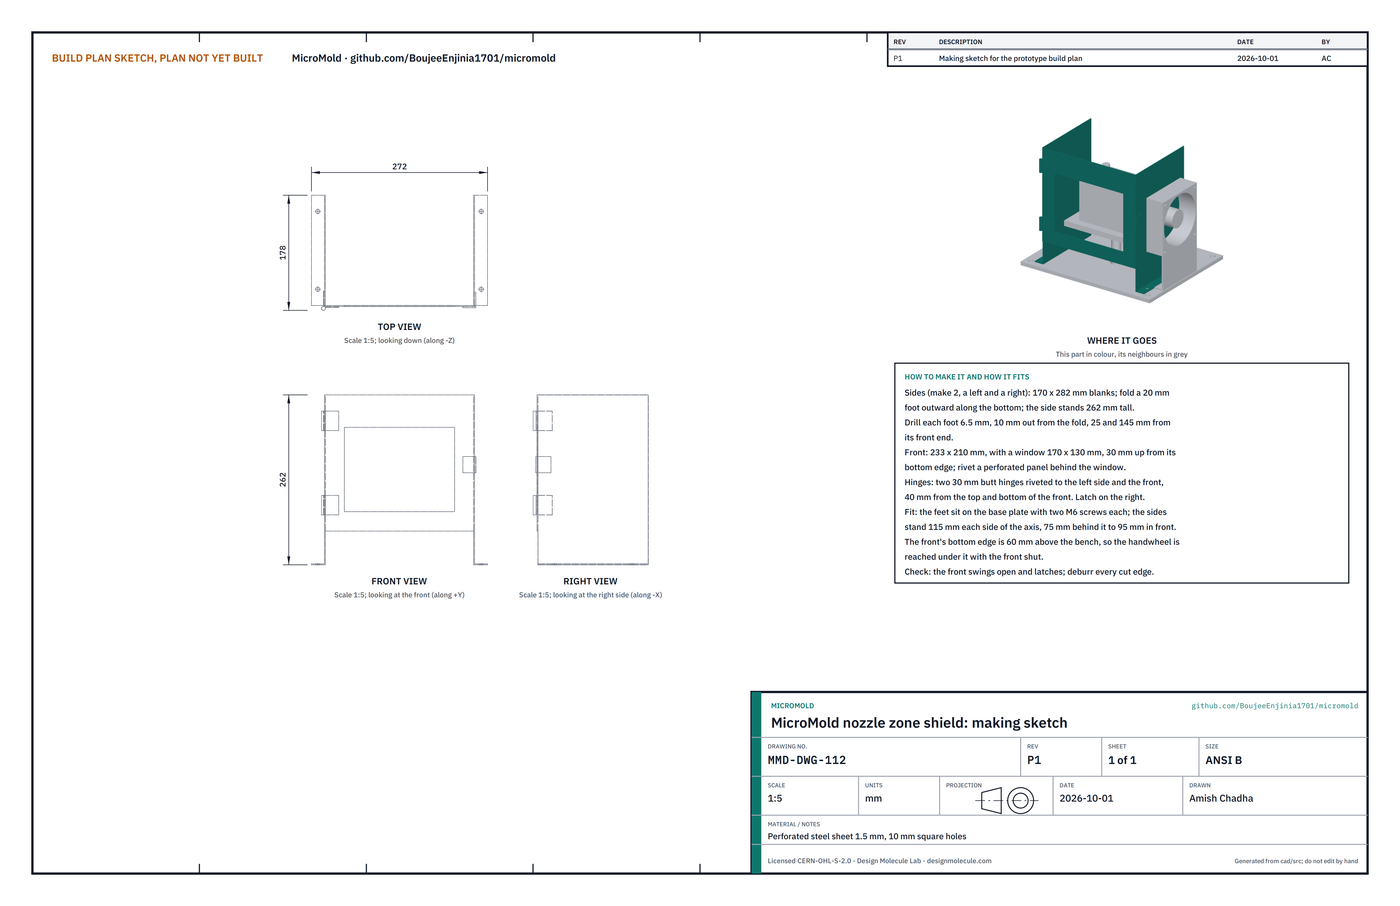
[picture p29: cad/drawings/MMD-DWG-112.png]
Figure 20. Making sketch of the shield


*Figure 20. Nozzle zone shield making sketch (MMD-DWG-112).*

**What it is and what it is made from.** The perforated guard round the nozzle and mold, with a hinged front. Perforated steel sheet 1.5 mm with 10 mm square holes; two 30 mm butt hinges; a sprung latch.

**How to make it.**

1. Sides (make 2, a left and a right): cut 170 x 282 mm blanks. Fold a 20 mm foot outward along one long edge, 90 degrees, so the side stands 262 tall.
2. Drill each foot 6.5 mm, 10 out from the fold, 25 and 145 from its front end.
3. Front: cut 233 x 210 mm with a window 170 x 130 mm, 30 up from the bottom edge and centred. Rivet a perforated panel behind the window.
4. Rivet the two hinges to the left side's front edge and the front, 40 from the top and the bottom of the front. Rivet the latch to the right side and the front.
5. Deburr every cut edge.

**How it fits the parts next to it.**

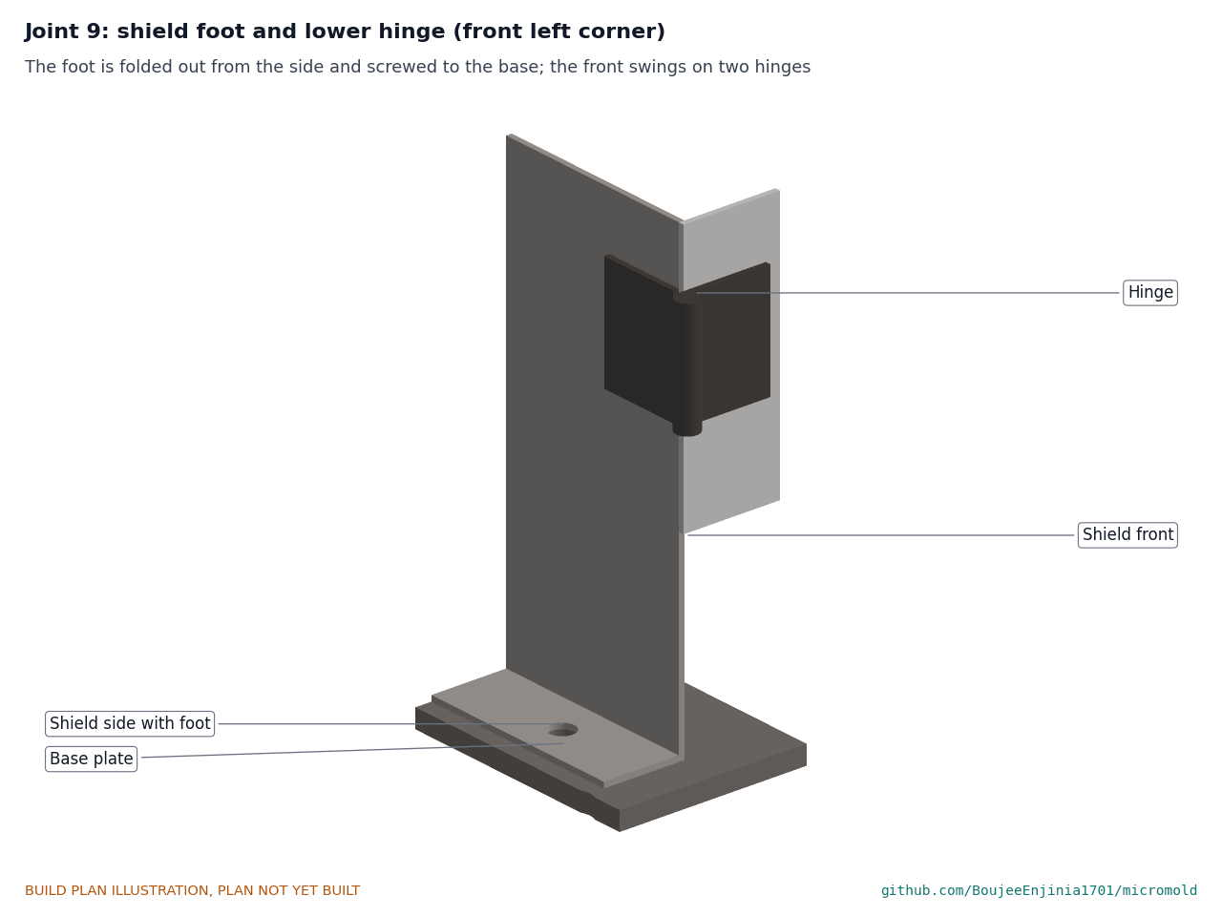
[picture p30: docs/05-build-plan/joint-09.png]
Figure 21. Joint 9: shield foot and lower hinge


*Figure 21. Each foot is screwed to the base plate with two M6 screws; the front swings open on its hinges.*

The sides stand 115 each side of the barrel axis, from 75 behind it to 95 in front. The front's bottom edge is 60 above the bench, so the handwheel is reached under it with the front shut.

**Check before moving on.** The front swings open fully and latches shut.

### 3.13 Fan bracket

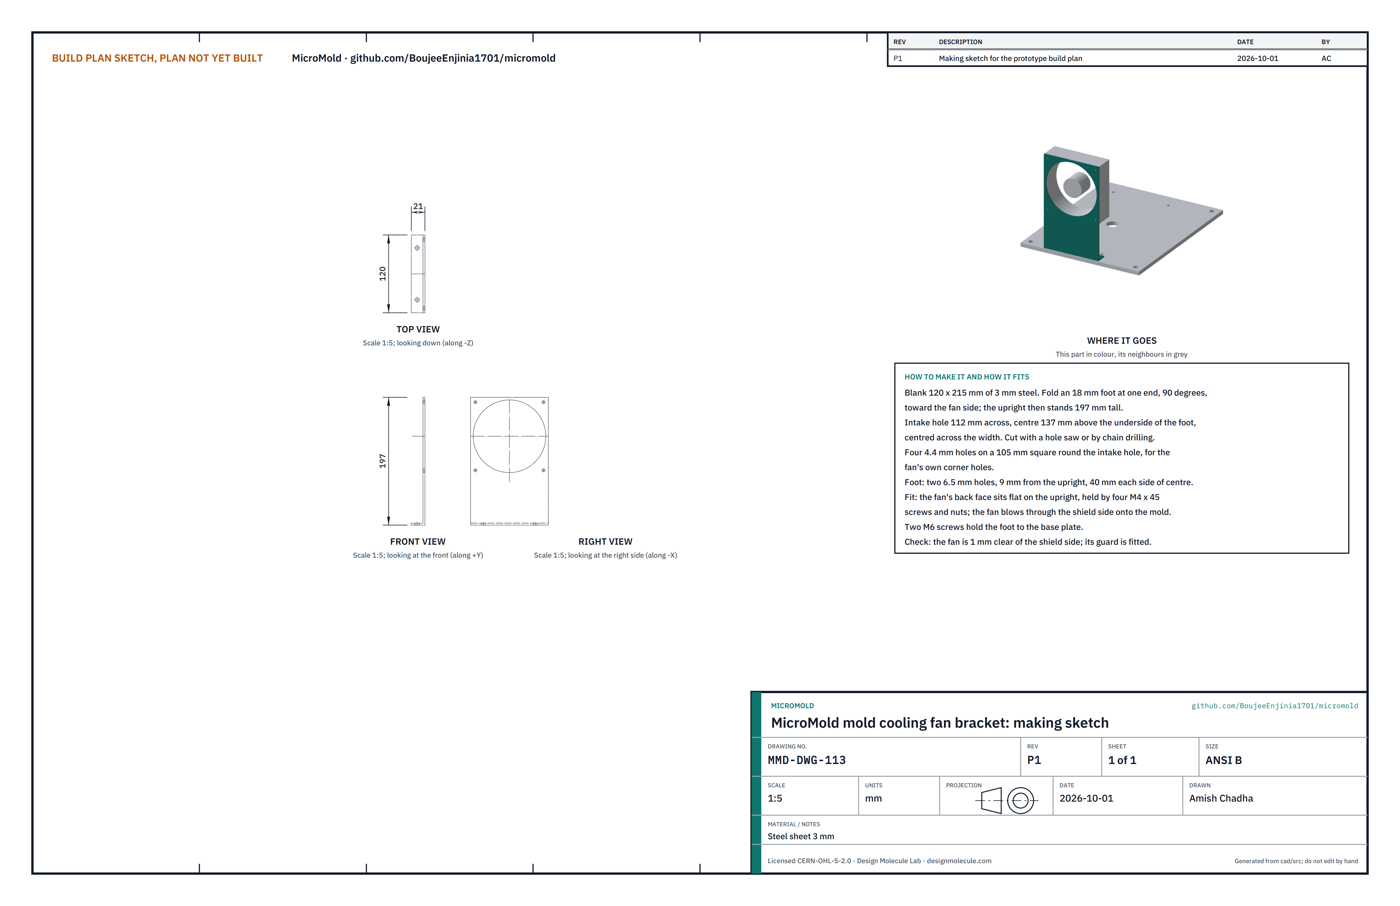
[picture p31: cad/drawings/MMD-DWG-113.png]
Figure 22. Making sketch of the fan bracket


*Figure 22. Fan bracket making sketch (MMD-DWG-113).*

**What it is and what it is made from.** The plate that holds the mold cooling fan beside the shield. Steel sheet 3 mm.

**How to make it.**

1. Cut a blank 120 x 215 mm. Fold an 18 mm foot at one end, 90 degrees, toward the fan side; the upright stands 197 tall.
2. Cut the 112 mm intake hole, its centre 137 above the underside of the foot, centred across the width.
3. Drill four 4.4 mm holes on a 105 mm square round the intake hole, for the fan's corner holes.
4. Drill two 6.5 mm holes in the foot, 9 from the upright, 40 each side of centre.

**How it fits the parts next to it.**

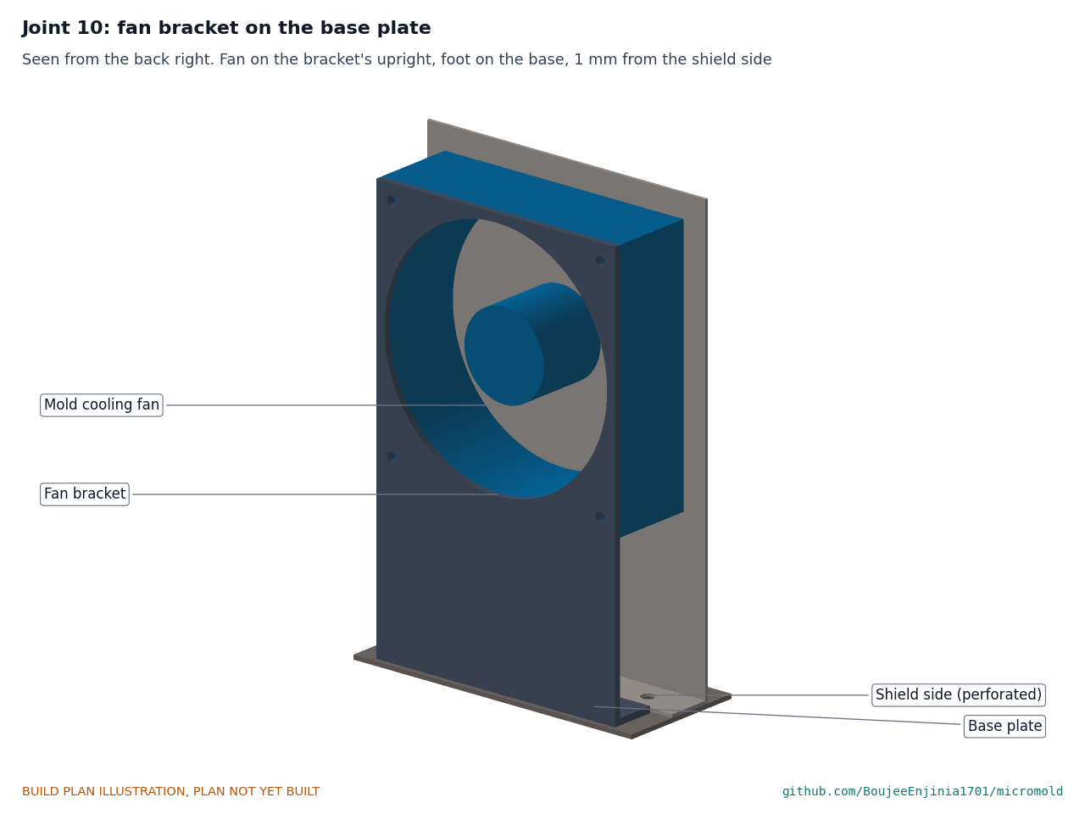
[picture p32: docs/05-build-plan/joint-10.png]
Figure 23. Joint 10: fan bracket on the base plate


*Figure 23. The fan's back sits flat on the upright on four M4 x 45 screws; the foot is screwed to the base plate; the fan is 1 mm from the shield side.*

**Check before moving on.** The fan's finger guard is fitted on its intake side, and the fan blows toward the mold.

### 3.14 Fume hood and hood arm

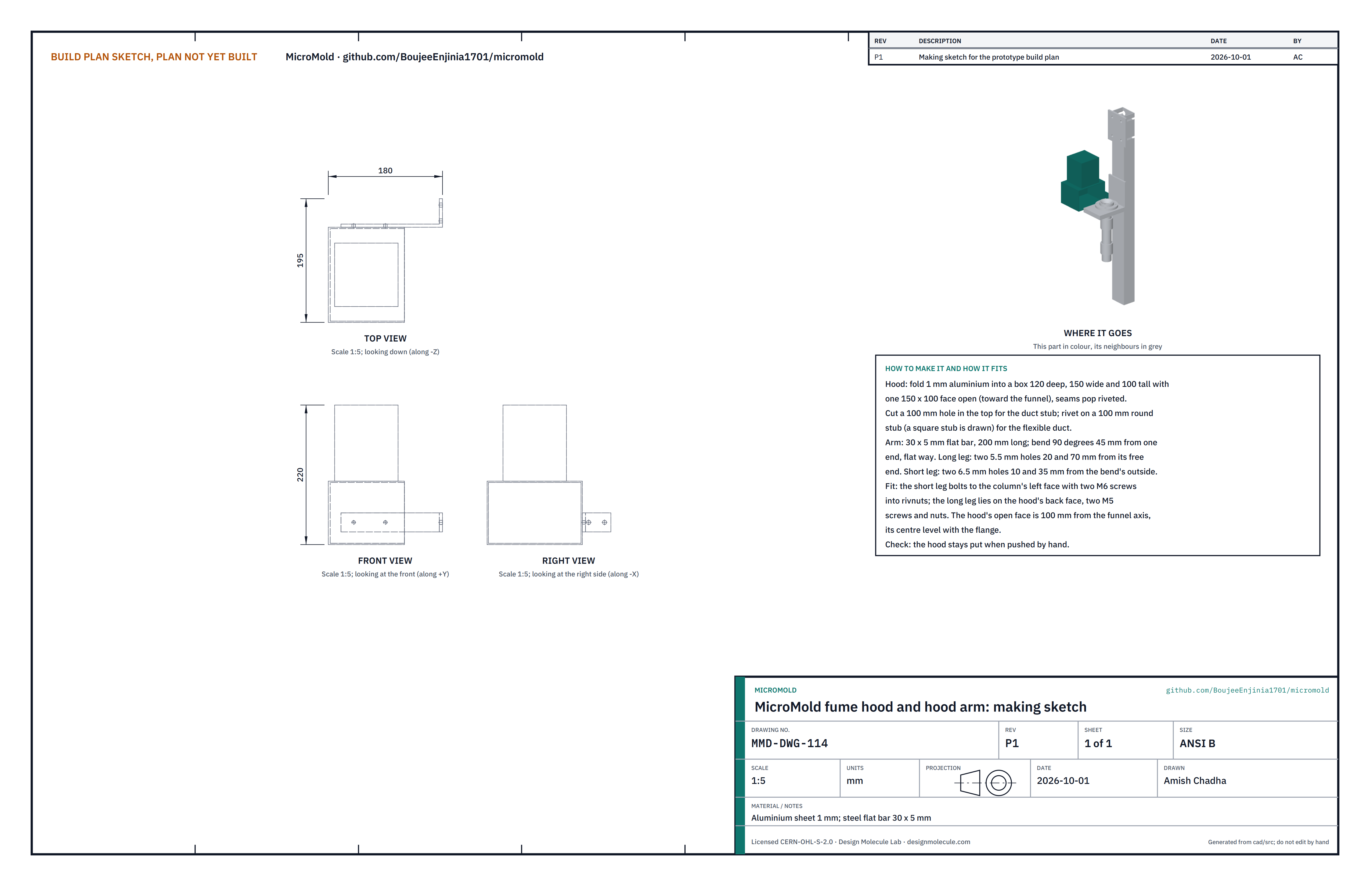
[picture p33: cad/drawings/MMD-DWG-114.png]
Figure 24. Making sketch of the hood and arm


*Figure 24. Fume hood and hood arm making sketch (MMD-DWG-114).*

**What they are and what they are made from.** The hood that draws fumes from the funnel into a duct, and the arm that holds it to the column. Aluminium sheet 1 mm; steel flat bar 30 x 5 mm.

**How to make them.**

1. Hood: fold a box 120 deep, 150 wide and 100 tall with one 150 x 100 face open; pop rivet the seams.
2. Cut a 100 mm hole in the top and rivet on a 100 mm round duct stub (the model draws it square).
3. Arm: cut 200 mm of flat bar and bend it 90 degrees the flat way, 45 from one end.
4. Long leg: two 5.5 mm holes, 20 and 70 from its free end. Short leg: two 6.5 mm holes, 10 and 35 from the outside of the bend.
5. Drill the hood's back face through the long leg's holes.

**How they fit the parts next to them.**

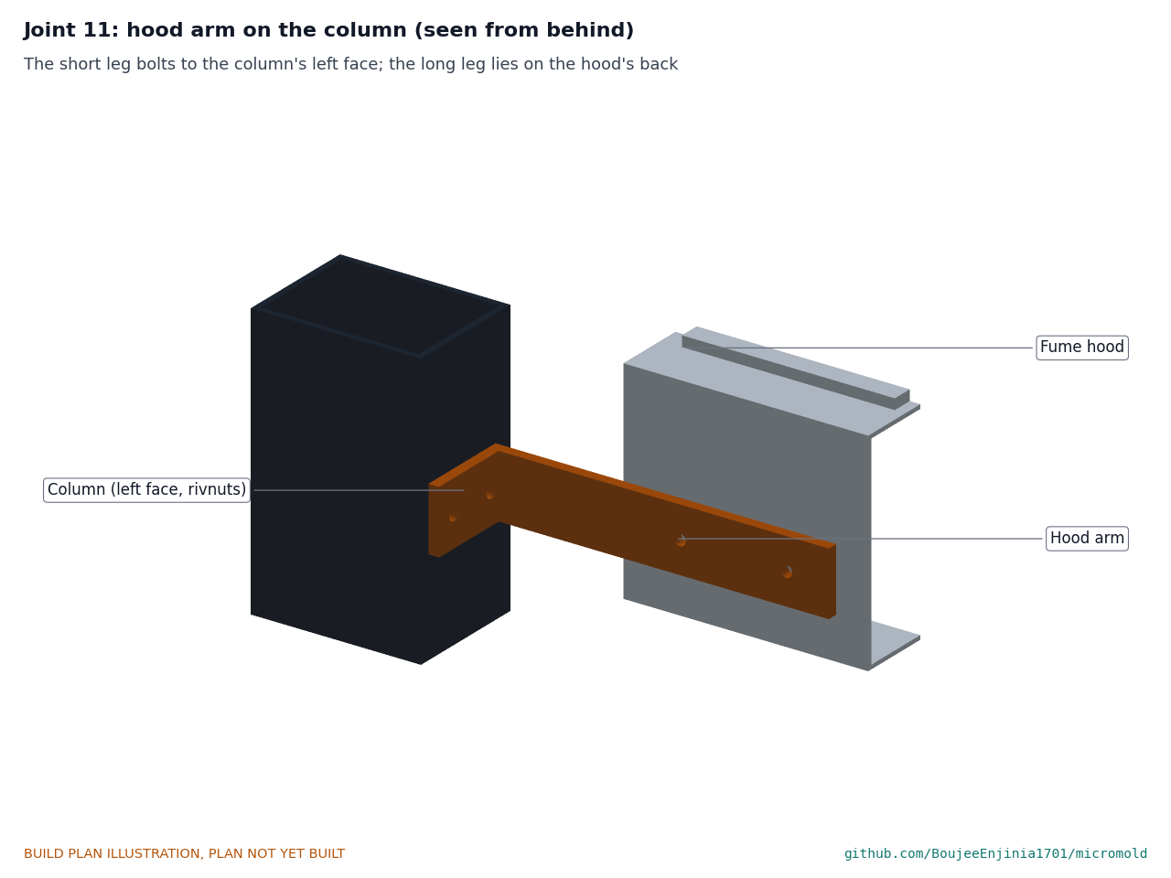
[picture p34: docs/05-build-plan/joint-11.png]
Figure 25. Joint 11: hood arm on the column, seen from behind


*Figure 25. The short leg bolts to the column's left face with two M6 screws into the rivnuts; the long leg lies on the hood's back, two M5 screws and nuts.*

The hood's open face is 100 from the funnel axis, its centre level with the barrel flange. The duct fan and 3 m of flexible duct take the air outdoors.

**Check before moving on.** The hood stays put when pushed by hand.

### 3.15 Test plaque mold

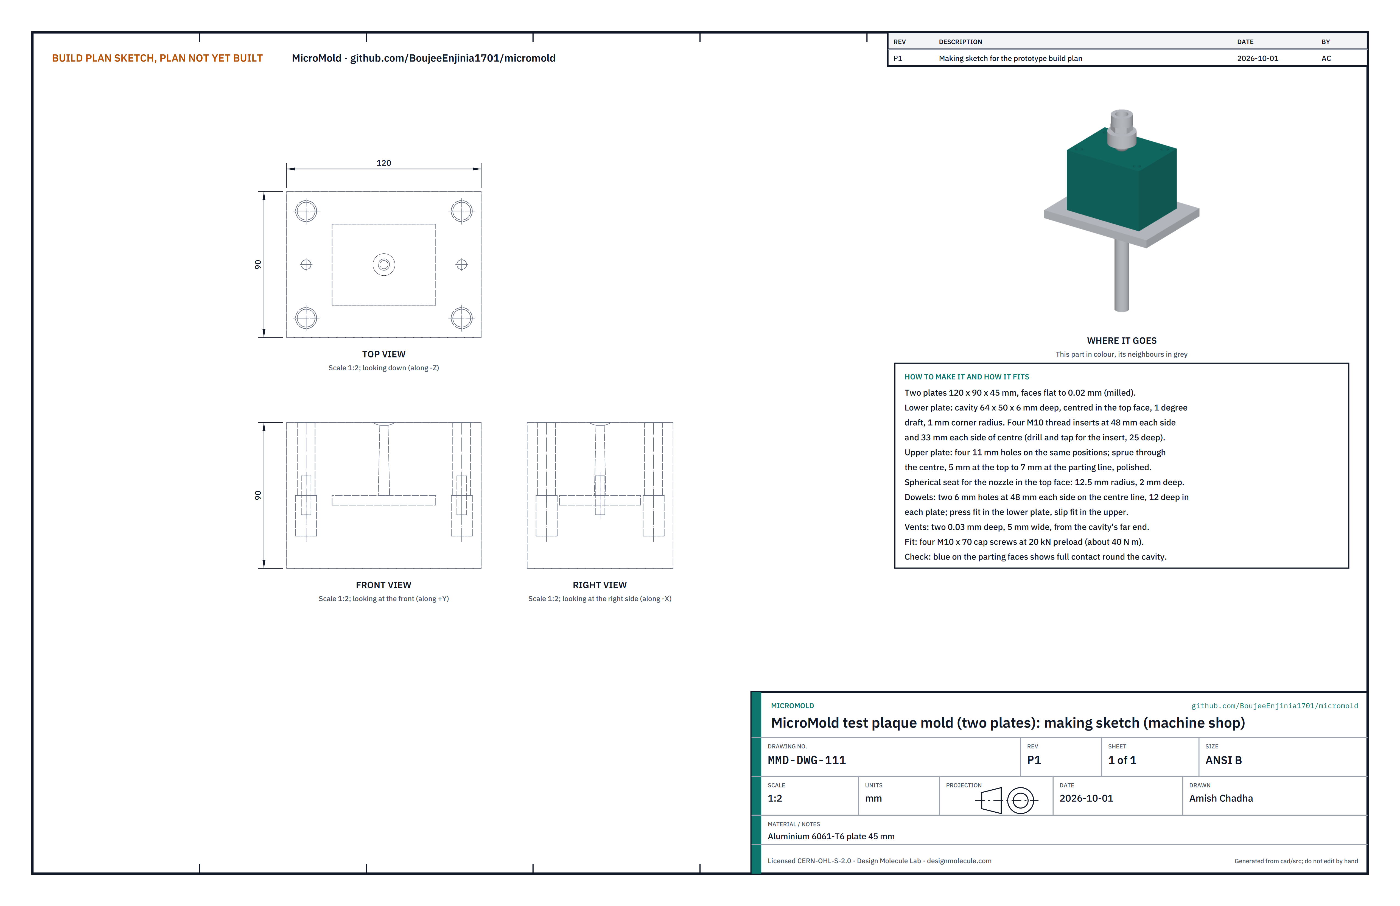
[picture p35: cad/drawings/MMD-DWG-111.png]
Figure 26. Making sketch of the mold


*Figure 26. Test plaque mold making sketch (MMD-DWG-111).*

**What it is and what it is made from.** Two aluminium plates that form a 64 x 50 x 6 mm test plaque, with the sprue through the upper plate. Aluminium 6061-T6, 45 mm plate, by a machine shop.

**How to make it.**

1. Mill two plates 120 x 90 x 45 mm, the parting faces flat to 0.02 mm.
2. Lower plate: mill the cavity 64 x 50 x 6 deep in the centre of its top face, with 1 degree of draft and 1 mm corner radii. Fit four M10 steel thread inserts, 25 deep, at 48 each side and 33 each side of centre.
3. Upper plate: drill four 11 mm holes at the same positions. Ream the sprue through its centre, 5 mm at the top to 7 mm at the parting face, and polish it. Cut the nozzle seat in the top face: a 12.5 mm spherical radius, 2 deep.
4. Dowels: two 6 mm holes on the centre line at 48 each side, 12 deep in each plate, press fit in the lower plate and slip fit in the upper. Fit the dowels in the lower plate.
5. Vents: two 0.03 mm deep, 5 mm wide, from the far end of the cavity.

**How it fits the parts next to it.**

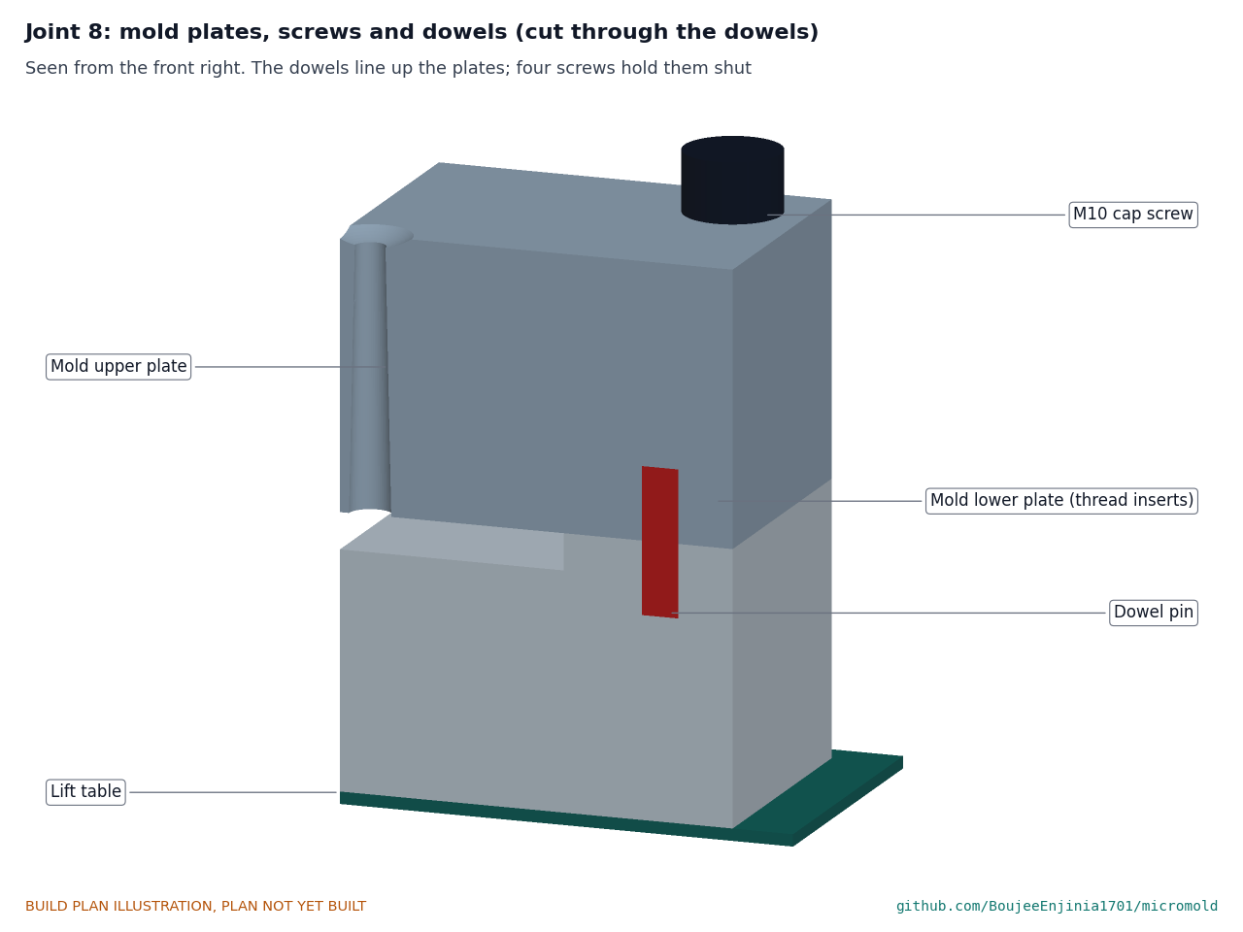
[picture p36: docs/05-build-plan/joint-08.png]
Figure 27. Joint 8: mold plates, screws and dowels, cut through the dowels


*Figure 27. The dowels line up the plates; four M10 x 70 cap screws hold them shut at about 40 N·m each (20 kN preload).*

The lower plate stands flat on the lift table; the nozzle seats in the upper plate's spherical seat (Figure 13). With the test mold (90 mm stack) seated, the table top is 102 above the bench.

**Check before moving on.** Engineer's blue on the parting faces shows full contact round the cavity.

### 3.16 Plunger rest

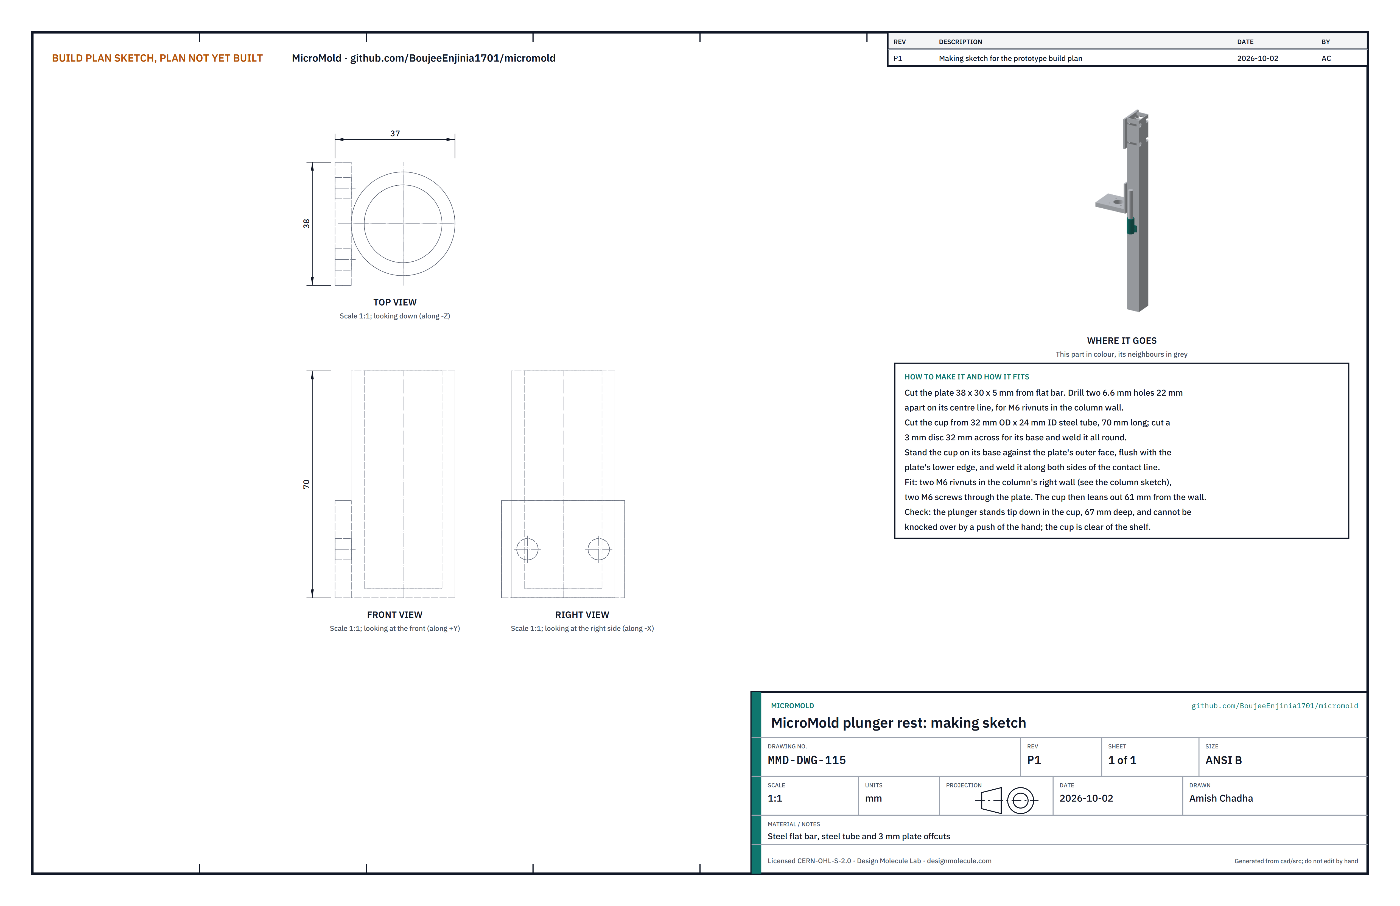
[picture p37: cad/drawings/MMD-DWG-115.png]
Figure 28. Making sketch of the plunger rest


*Figure 28. Plunger rest making sketch (MMD-DWG-115).*

**What it is and what it is made from.** A cup on the column's right-hand side that holds the plunger upright while the barrel is loaded, so the hot plunger is never laid on the bench. Steel flat bar 38 x 30 x 5 mm, steel tube 32 mm across with a 24 mm bore, and 3 mm plate.

**How to make it.**

1. Cut the plate 38 x 30 mm from 5 mm flat bar. Drill two 6.6 mm holes 22 apart on its centre line.
2. Cut 70 mm of the tube with square ends. Cut a 3 mm disc 32 mm across and weld it to one end all round, to make the cup.
3. Stand the cup on its base against the plate's outer face, flush with the plate's lower edge, and weld it along both sides of the line where they touch.
4. Clean up the welds and paint.

**How it fits the parts next to it.**

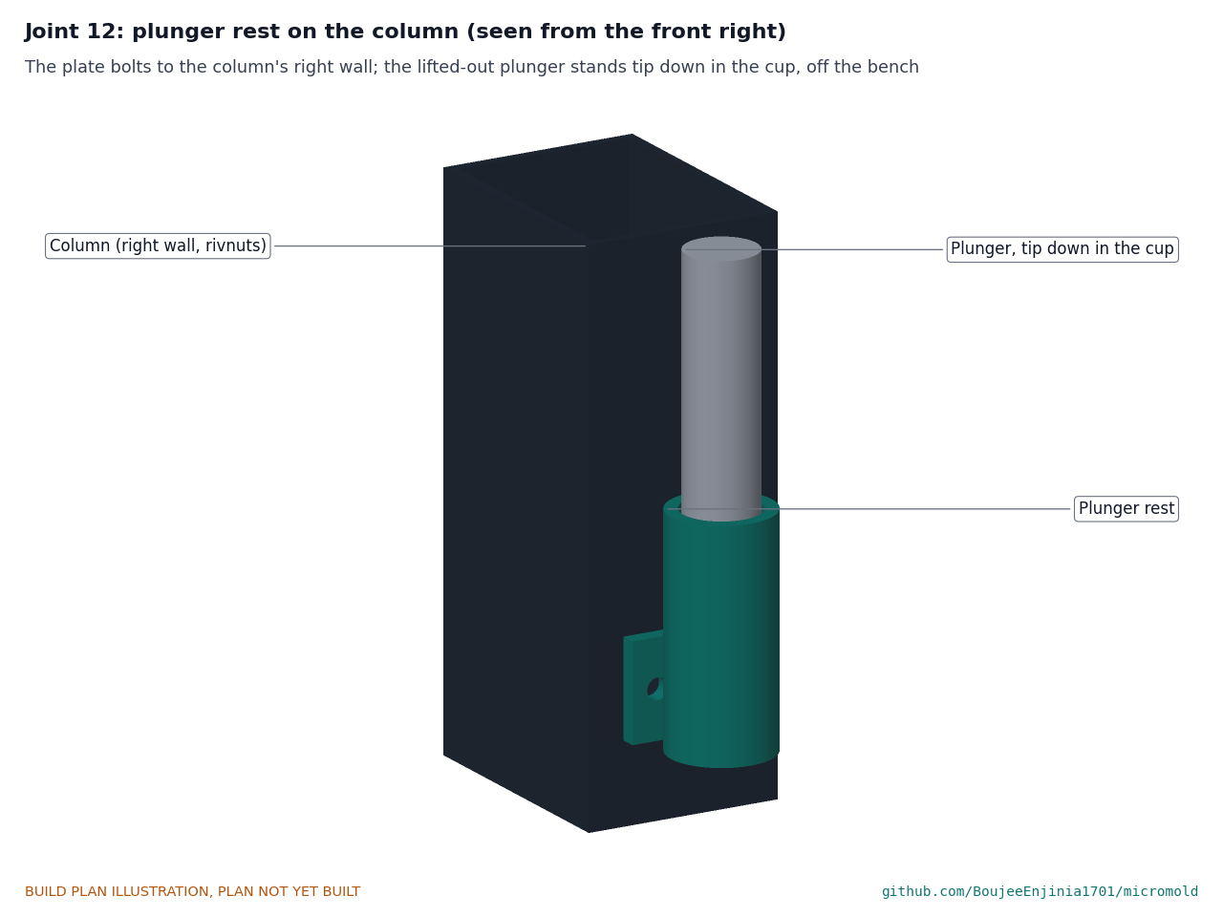
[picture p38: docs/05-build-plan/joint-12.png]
Figure 29. Joint 12: plunger rest on the column, seen from the front right


*Figure 29. The plate bolts to the column's right-hand face with two M6 screws into the rivnuts; the cup leans out 61 mm and holds the plunger's tip.*

The cup is 400 mm above the bench, level with the shelf, and clear of the shelf, the jacket and the shield. To load the barrel, let the ram run up, pull the ball-lock pin and lift the plunger out of its coupling, and stand it tip down in the cup (it stands 67 mm deep, top at 588 mm). Pour the flake into the funnel and tamp it, then lift the plunger out of the cup, push its top into the coupling and refit the pin. The tip is hot: use heat-resistant gloves.

**Check before moving on.** The plunger stands in the cup without being held and is not knocked over by a push of the hand; the rest does not move when pushed.

### 3.17 Bought components

Buy to specification, not brand. Line numbers are those of the bill of materials.

- **Arbor press (line 2).** 1 t, rack and pinion, 28 mm square ram 255 mm or longer with 150 mm of engaged travel, pinion pitch radius about 20 mm, a head casting that can be cut from the frame with a flat back face. Prepared as section 3.5.
- **Ratchet handle (line 2).** 1/2 in drive, about 450 mm long, reversible.
- **Torque-limiting socket (line 21).** 1/2 in drive, click or slip type, set to 180 N·m, rated for 200 N·m or more, accurate to about 10 per cent.
- **Load cell (line 4).** 10 kN compression cell, 56 mm across, with a top M12 stud and a base flange with three through holes for M5 screws (46 mm circle assumed), an HX711-class amplifier and a 4-digit display.
- **Band heaters (lines 7 and 8).** Two 300 W mica bands, 42 mm bore x 50 wide, and one 100 W band, 24 mm bore x 18 wide, all for the local mains voltage, with ceramic terminal blocks.
- **Mica pads and washers (line 9).** Four 15 x 15 x 3 mm pads; four mica washers for M8.
- **Control box (line 13).** Earthed metal enclosure with a fused IEC inlet, a double-pole switch, two PID controllers with set point limits, two 25 A solid-state relays on a heat sink, a 280 °C independent thermal cut-out, a switched outlet for the duct fan and the mold fan, and the load cell display.
- **Wiring (line 14).** Wire rated 250 °C in glass-fibre sleeving for the heaters, two K-type thermocouples (one in the barrel well, one under the nozzle band), earth leads to the frame, the jacket, the shield and the fan bracket.
- **Duct fan and duct (line 17).** 100 mm inline fan, 170 m³/h or more in free air, 3 m of 100 mm aluminium flexible duct and clamps.
- **Mold cooling fan (line 18).** 120 x 120 x 38 mm mains axial fan, about 18 W, corner holes on a 105 mm square, with a finger guard.
- **Fixings (lines 9 to 20).** Four M10 x 25 countersunk screws (head); four M8 x 30 cap screws (flange); four M5 x 25 screws and 14 mm spacers (jacket); three M5 x 12 low-head screws and three M5 x 12 screws (spacer); four M10 x 70 class 8.8 cap screws, four M10 thread inserts and two 6 x 24 mm dowels (mold); a 6 mm ball-lock pin and a 6 mm roll pin; eight M6 x 12 screws (shield feet, fan bracket); two M6 rivnuts and two M6 x 16 screws each for the hood arm and the plunger rest; two M5 screws and nuts (hood); four M4 x 45 screws and nuts (fan); four M10 bench bolts with washers; a 2 mm steel thrust washer for 20 mm; copper anti-seize and medium threadlocker.

## 4. Putting it together

In each picture the parts already fitted are grey and the part being fitted is in colour, with an arrow showing the way it goes in. Assemble on a workbench without the bench hole until step 13; keep the lift table at its highest until then, so the screw stays above the base plate. The barrel goes in from above, so it is fitted before the press head.

### Step 1: weld the column to the base plate

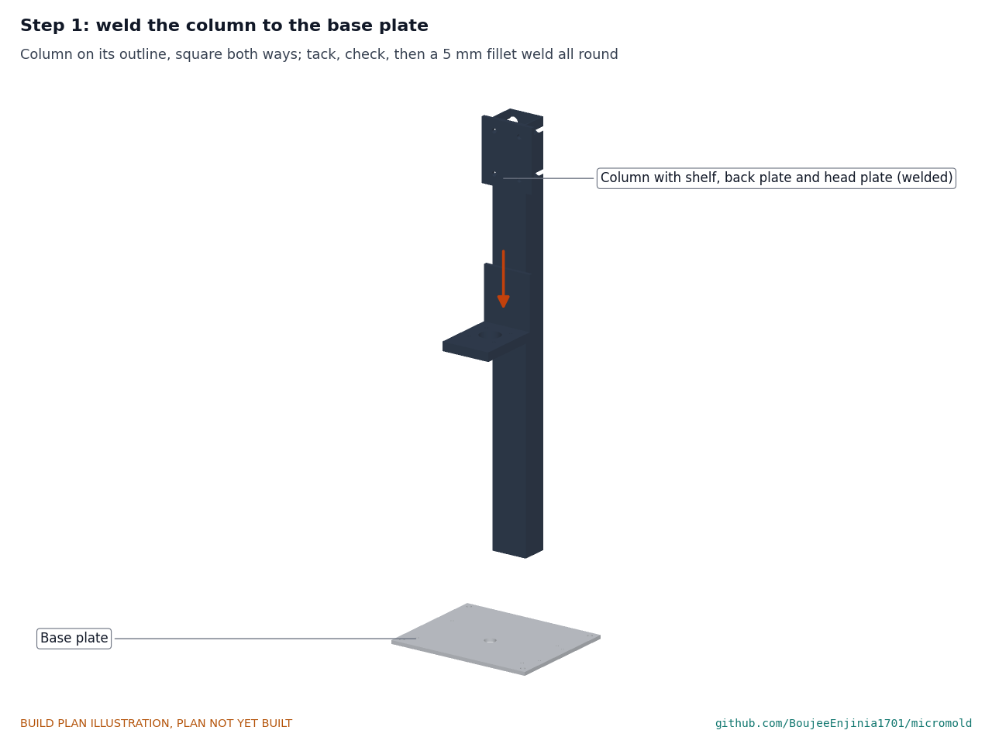
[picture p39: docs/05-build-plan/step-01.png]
Step 1


Stand the column weldment on its outline, square to the plate both ways. Tack weld, check square again, then weld a 5 mm fillet all round. **Hold point:** the column is square to the plate within 1 mm over its height.

### Step 2: lift table and handwheel nut

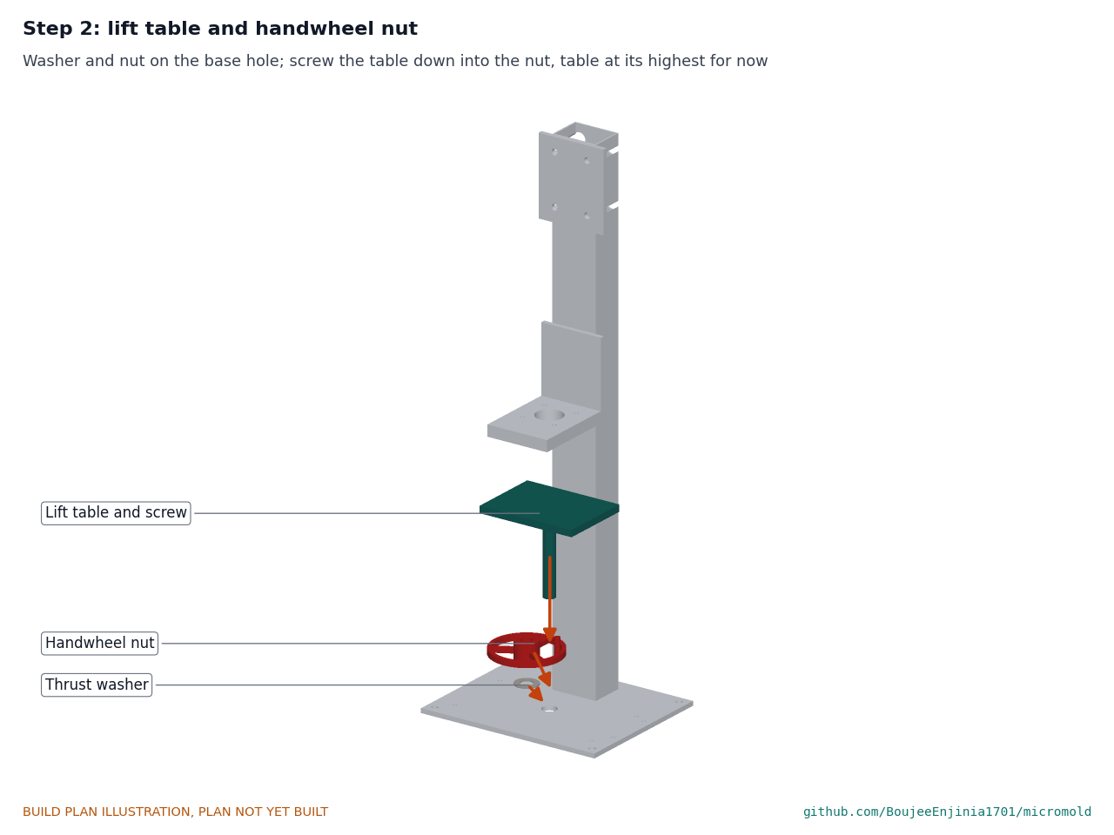
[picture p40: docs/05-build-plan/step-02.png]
Step 2


Lay the thrust washer over the lift screw hole and the handwheel nut on it. Screw the table's screw down into the nut by turning the handwheel, with the table's back edge toward the column, until the table is at its highest (160 above the bench).

### Step 3: nozzle onto the barrel

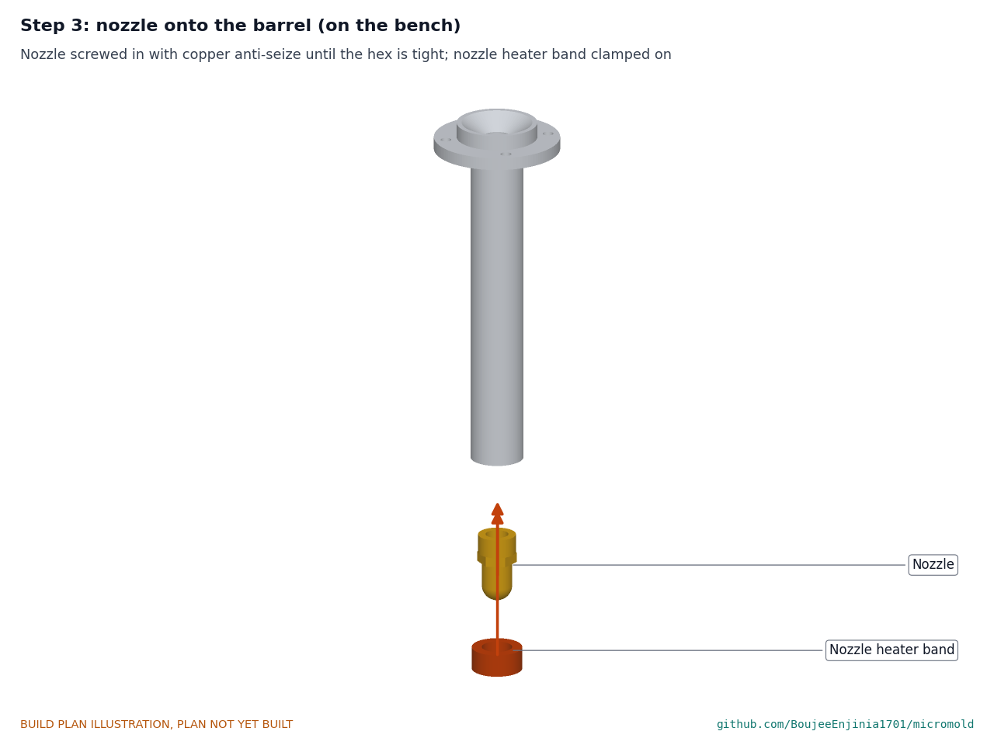
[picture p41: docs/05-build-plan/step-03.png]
Step 3


On the bench, screw the nozzle into the barrel with copper anti-seize until the hex is tight. Clamp the 100 W band round the nozzle body, terminals to the back.

### Step 4: barrel into the shelf

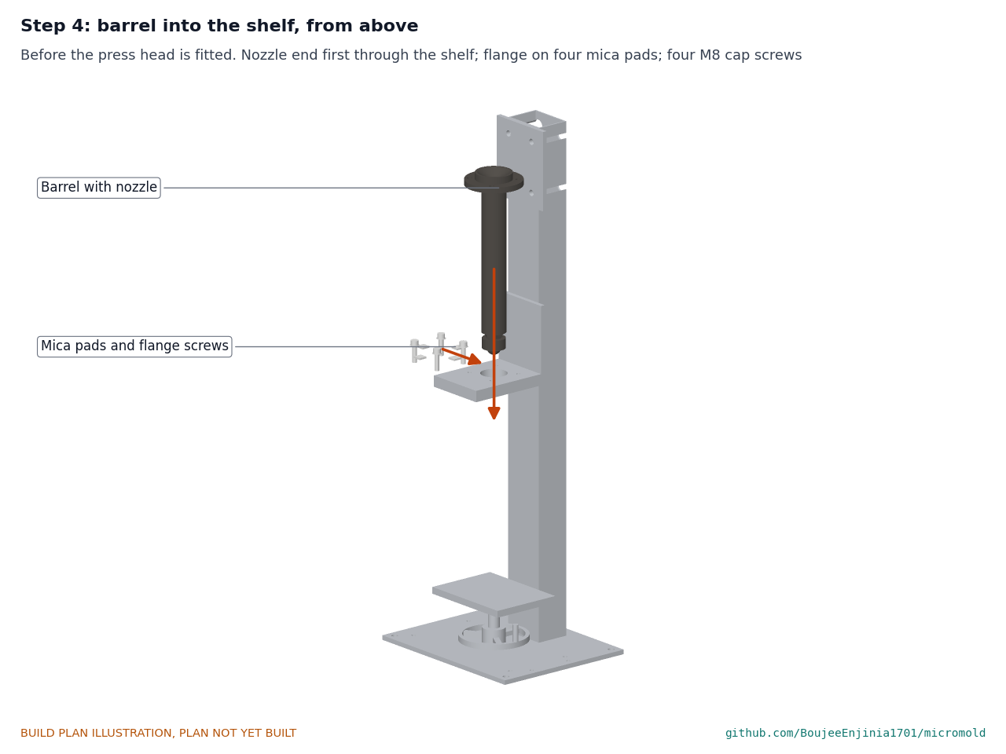
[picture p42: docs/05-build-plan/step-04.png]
Step 4


Lay the four mica pads on the shelf round the hole. Lower the barrel, nozzle first, through the hole from above until the flange sits on the pads; the nozzle and its band pass the 46 mm hole, the band heaters would not. Fit the four M8 cap screws with mica washers, snug (about 10 N·m); they only hold the barrel down.

### Step 5: band heaters and jacket

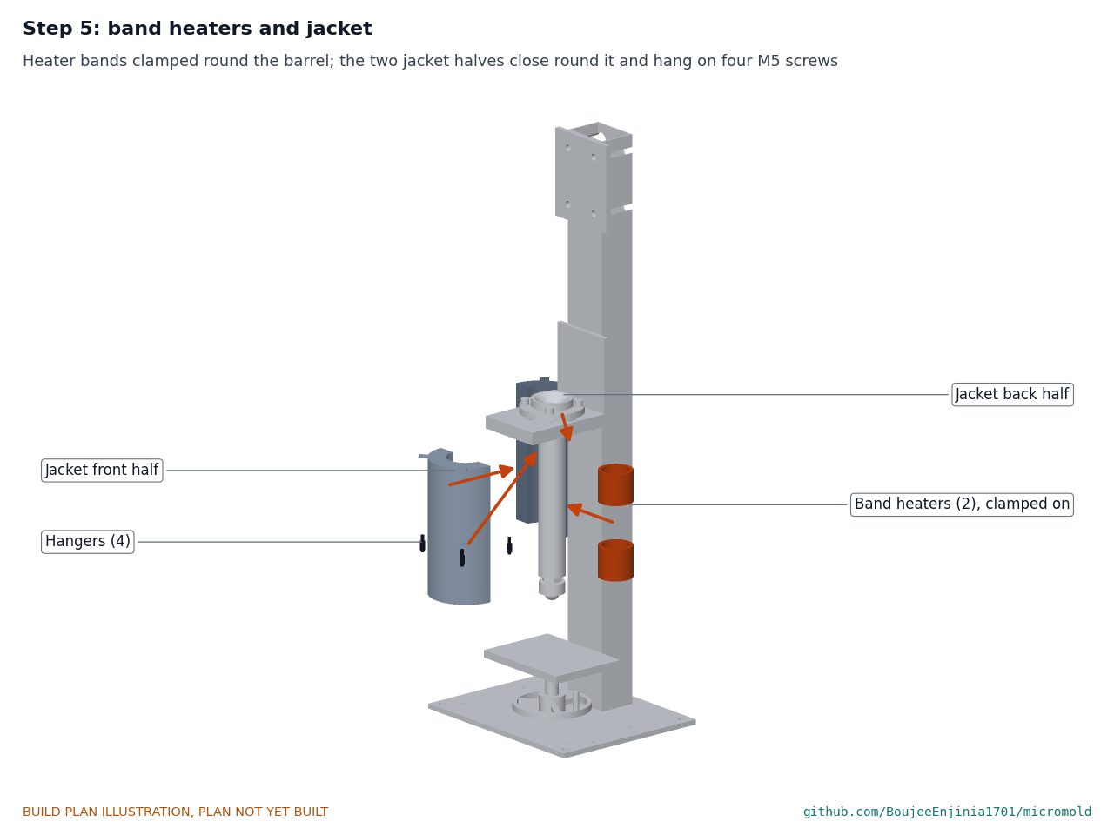
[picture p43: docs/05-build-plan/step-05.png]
Step 5


Clamp the two 300 W bands round the barrel, centred 60 and 180 above its lower end, terminals to the back. Close the two jacket halves round the barrel, back half (with the lead notches) behind, and hang each on two M5 screws through its tabs and spacers into the shelf.

### Step 6: press head onto the head plate

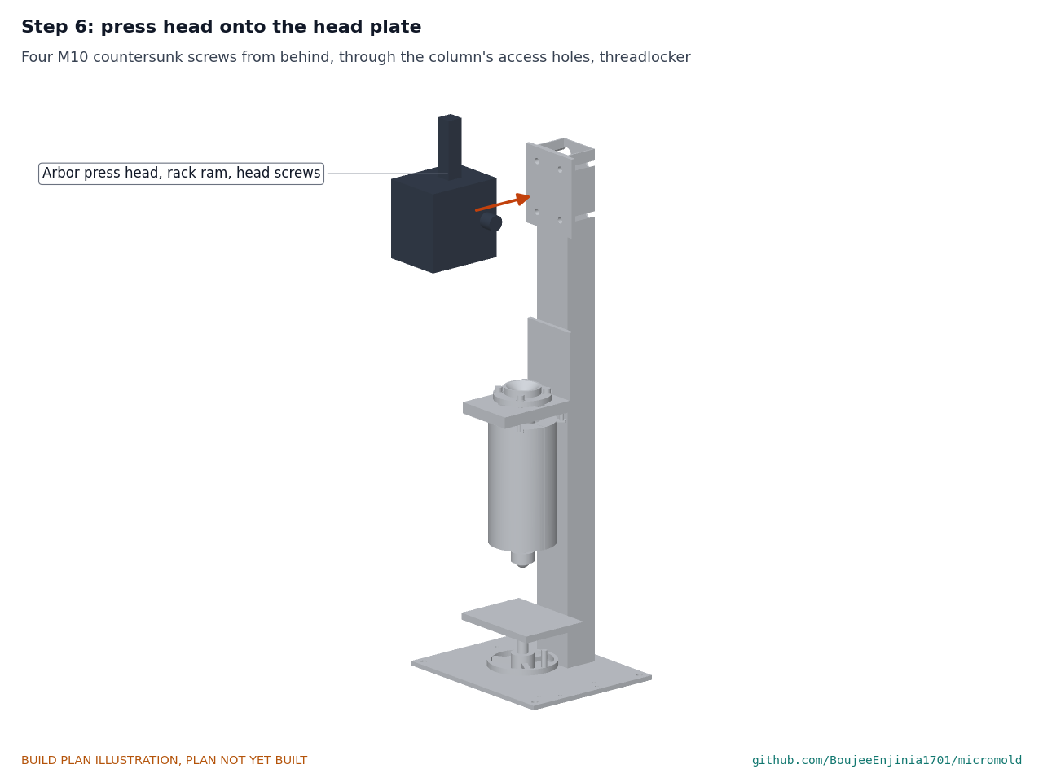
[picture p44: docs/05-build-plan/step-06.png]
Step 6


Hold the head against the head plate and fit four M10 countersunk screws from behind, through the column's access holes, with medium threadlocker. Tighten to about 45 N·m with a hex key through the holes.

### Step 7: ratchet adapter, torque-limiting socket and handle

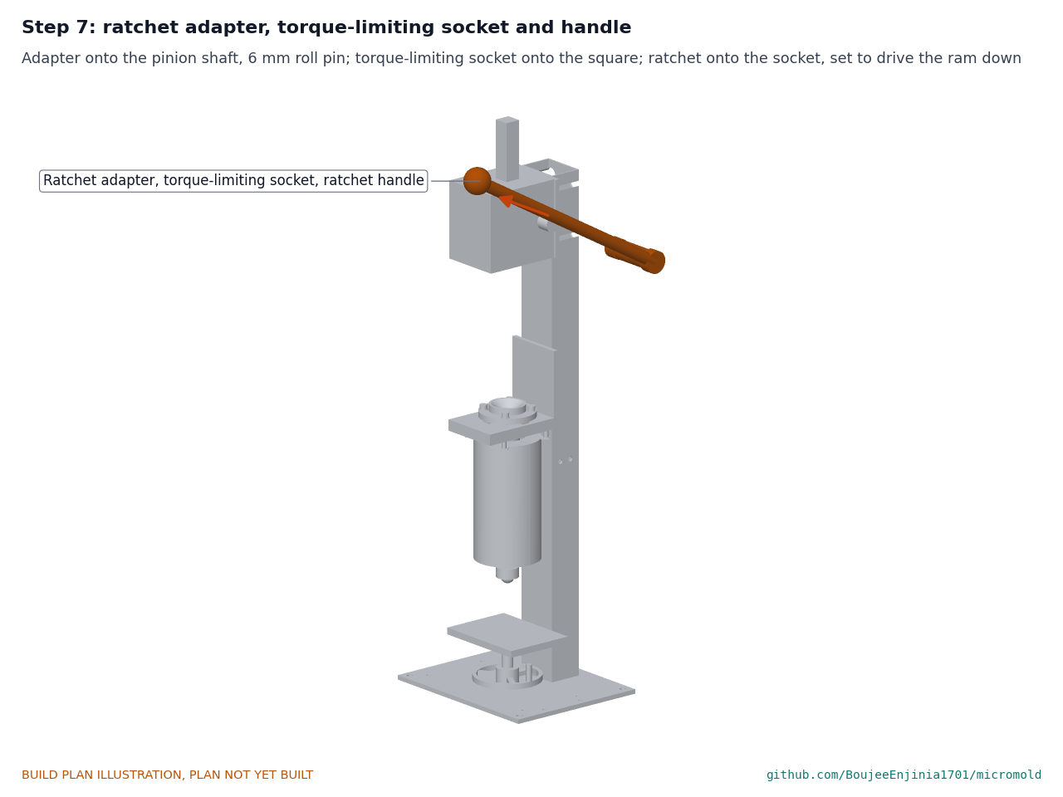
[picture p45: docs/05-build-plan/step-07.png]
Step 7


Slide the adapter onto the right-hand end of the pinion shaft and fit the roll pin. Push the torque-limiting socket onto the square, set to 180 N·m, then push the ratchet onto the socket and set it so a pull toward you drives the ram down. Turn the ram to its highest.

### Step 8: plunger unit

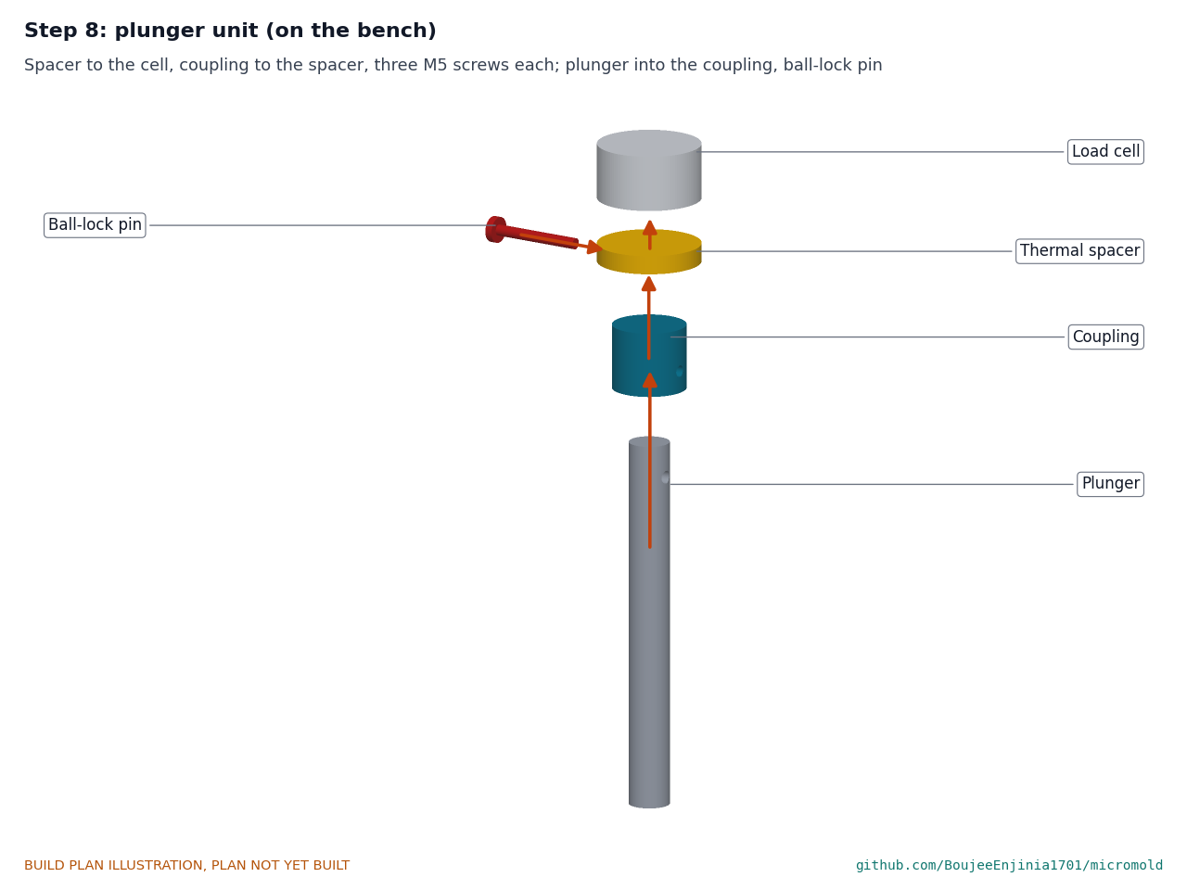
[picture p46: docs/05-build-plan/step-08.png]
Step 8


On the bench, screw the coupling under the spacer (three low-head screws) and the spacer under the load cell (three screws through the cell's flange). Push the plunger up into the coupling and fit the ball-lock pin.

### Step 9: plunger unit onto the ram

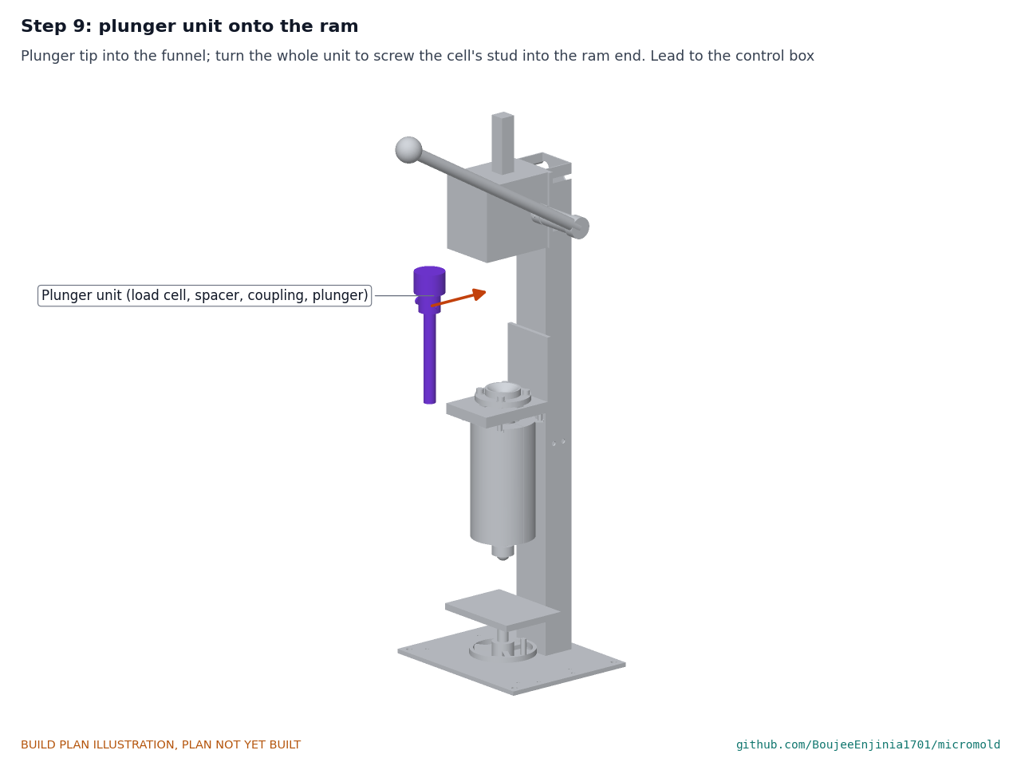
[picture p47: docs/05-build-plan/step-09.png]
Step 9


With the ram at its highest, set the plunger's tip into the funnel and turn the whole unit to screw the load cell's stud into the ram end. Run the load cell lead along the column to the control box. **Hold point:** the plunger runs the full 150 mm stroke by hand with no binding.

### Step 10: nozzle zone shield

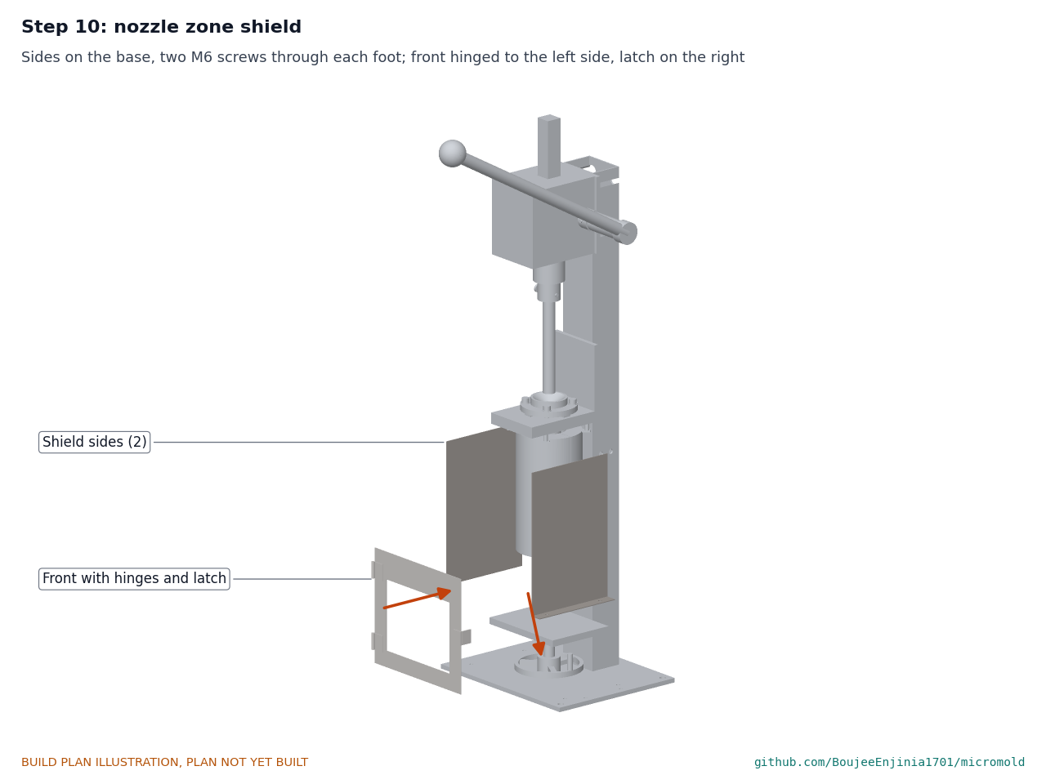
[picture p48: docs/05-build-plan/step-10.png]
Step 10


Stand the sides on the base plate and fit two M6 screws through each foot. Check that the front swings open and latches.

### Step 11: mold cooling fan

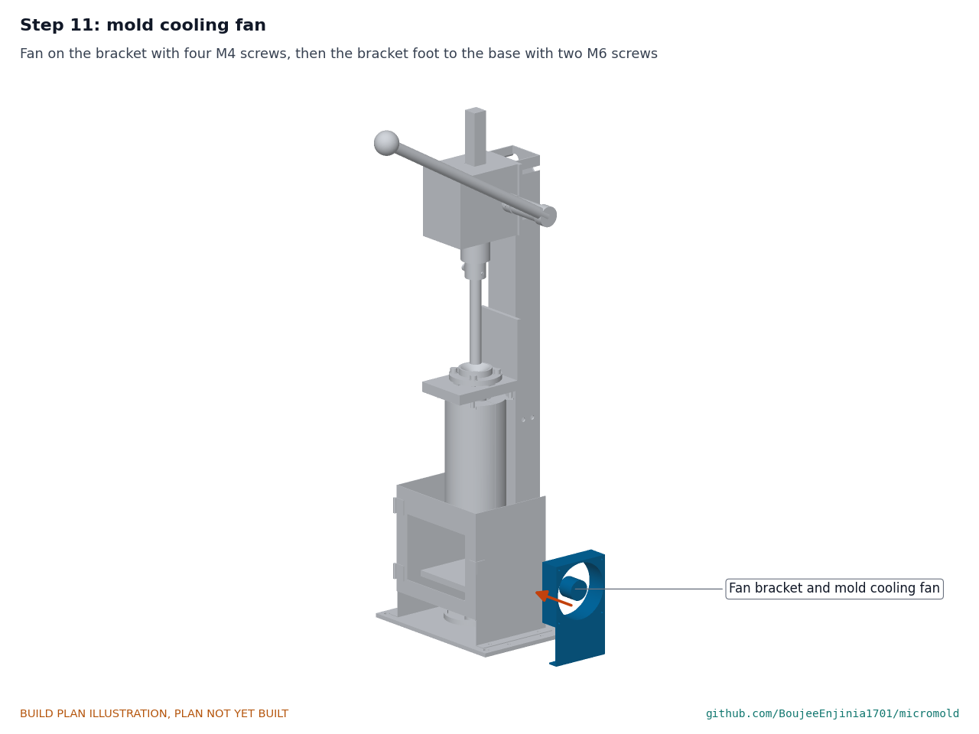
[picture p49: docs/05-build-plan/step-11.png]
Step 11


Fix the fan to the bracket with four M4 x 45 screws and nuts, then the bracket's foot to the base plate with two M6 screws.

### Step 12: fume hood and plunger rest

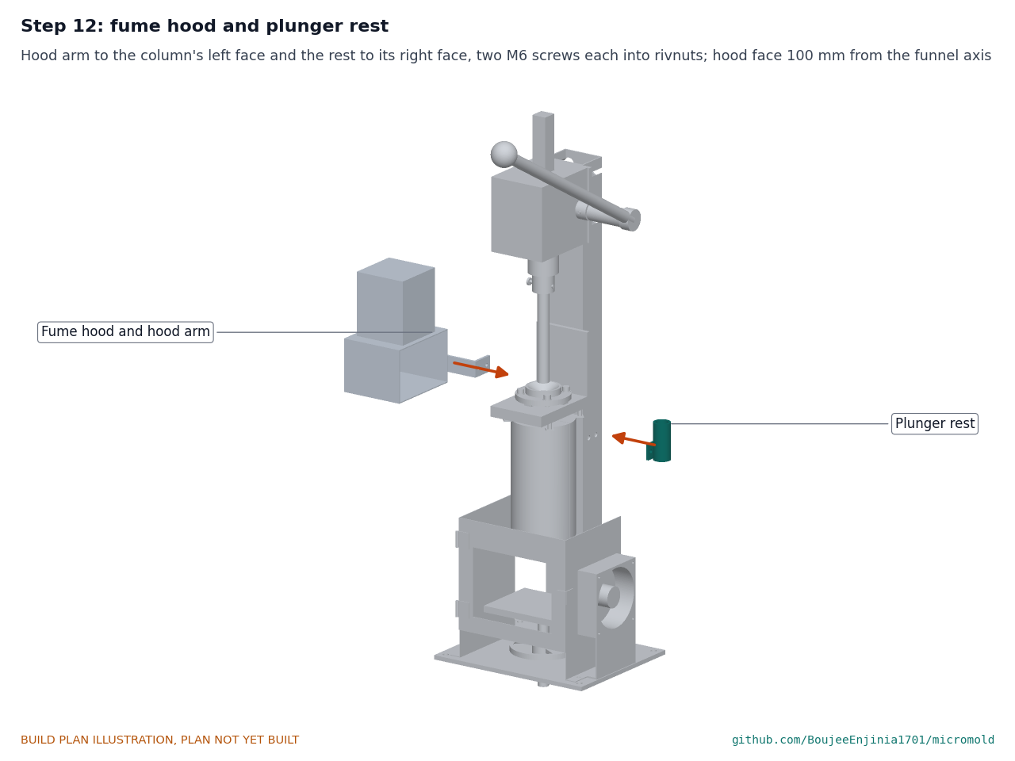
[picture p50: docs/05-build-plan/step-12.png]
Step 12


Bolt the arm's short leg to the column's left face with two M6 screws into the rivnuts. Fix the duct stub to the flexible duct and run it to the duct fan. Bolt the plunger rest to the column's right face with two M6 screws into the rivnuts.

### Step 13: onto the bench, and wiring

Step 13

Drill a 25 mm hole through the bench top where the lift screw will go, with at least 60 mm clear below it. With two people, lift the press onto the bench with the screw over the hole and bolt the base plate down with four M10 bolts. Set the control box to the left. A qualified electrician wires the inlet, switch, RCD supply, controllers, relays, cut-out, heaters, thermocouples and fan outlet, and earths the frame, jacket, shield and fan bracket. **Hold point:** safety stop S1.

### Step 14: test mold onto the table

Step 14

Open the shield front. Lower the table, stand the bolted mold on it centred under the nozzle, and raise the table with the handwheel until the nozzle seats in the mold. Shut the front. **Hold point:** safety stops S2 to S4 before any heating or injection.

## 5. First checks

These are the checks a TRL 4 test report would record; this plan only lists them. Requirement numbers are those of MMD-REQ-001.

*Table 2. First checks.*

| Check | Requirement | How | Pass when |
| --- | --- | --- | --- |
| Size, handle height and mass | R9 | Measure the footprint and the handle's top at the start of a pull; weigh the press without the control box | 350 x 300 mm or less; 1,100 mm or less (1,094 mm by the model); 40 kg or less (39.8 kg estimated) |
| Plunger travel | R2 | Turn the handle through a full stroke, cold | 150 mm of travel, 120 mm in the bore, no binding; about four pulls |
| Mold stack range | R7 | Seat a 30 mm and a 120 mm block on the nozzle with the handwheel | Both seat with at least 10 mm of travel to lower them |
| Electrical safety | R12 | Electrician's inspection: earth continuity, insulation, RCD trip | All pass; the RCD trips at 30 mA or less |
| Temperature control and cut-out | R4 | Heat both zones empty to 220 °C, then raise the cut-out's test set point | Each zone holds within 5 °C; the cut-out opens the heaters; set points above 260 °C are refused |
| Warm-up | R5 | Time from cold to 220 °C, barrel zone | 15 min or less (12.3 min estimated) |
| Touch temperature | R11 | Surface thermometer on the guard after 30 min at 220 °C | 60 °C or less (48 °C estimated) |
| Supply current | R10 | Clamp meter on the supply with everything running | 1 kW or less; 10 A or less at 120 V |
| Hood flow | R13 | Vane anemometer across the hood face | About 124 m³/h; smoke from a smoke pencil at the funnel goes into the hood |
| Overload limit | R3 | With the barrel cold, pull the handle past the socket's setting while watching the load cell | The socket slips at about a 400 N pull; the cell never reads above 8.3 kN |
| Melt pressure | R3 | Load cell reading with 250 N on the handle (a spring balance on the grip), barrel full of melt | 3.4 kN or more on the cell (8.9 MPa) |

## 6. Safety stops

Stop at each point. Carry on only when everything listed is true.

- **S1. Before the press is connected to the mains.** A qualified electrician has wired and inspected the control box to local code: fused inlet, double-pole switch, RCD or GFCI supply, independent cut-out in series with both heater relays, 250 °C wire at the barrel, every metal part earthed. Heater leads are clear of the plunger, ram and handle in every position.
- **S2. First heat, with no plastic.** Attended the whole time, hood running, shield shut, nothing flammable within 1 m. Both zones to 220 °C; stop and switch off at the inlet if any reading runs away, smoke appears or the guard passes 60 °C.
- **S3. Before any plastic goes in, and every time the barrel is loaded.** The resin is HDPE, PP, LDPE or PS flake from injection-molded items, clean and dry; never PVC or unknown plastics. Heat-resistant gloves, long sleeves and eye protection are on. The hood fan runs whenever the heaters are on. The plunger is lifted out on its pin and stood in the rest, never laid on the bench; its tip is hot.
- **S4. Before every injection.** Mold screws at their torque, the nozzle seated, the shield front shut and latched, faces away from the axis. Pull steadily with no more than about 250 N. The torque-limiting socket, set to 180 N·m, slips at about a 400 N pull so that the ram stays under the press rating (about 22 MPa at most, against 35 MPa without it); if it slips, stop and release the pull rather than pulling harder. Check the socket's setting before the first injection of each day. Release the ratchet pawl only with the handle in hand.
- **S5. Before opening the mold.** The fan has run for at least 1 min after the hold; lower the table before opening the front; gloves on. The sprue and plaque are hot.
- **S6. Before leaving the press.** Heaters off at the inlet; the barrel left to cool with the hood running.

## 7. Tools, skills and workspace

**Tools.** Angle grinder with cutting and grinding discs; hacksaw or bandsaw; bench drill with a vice; drills 3 to 22 mm and a 25 mm hole saw or step drill; 112 mm hole saw; countersink; taps M5, M6, M8, M10 and M12 with tap drills; rivnut tool; pop rivet tool; aviation snips; sheet folder or two lengths of steel angle clamped in a vice; MIG or stick welder for steel up to 20 mm; engineer's square, steel rule, calipers, scriber, centre punch; files and deburring tool; spanners, hex keys (including a long 6 mm key for the head screws) and a torque wrench to about 50 N·m; multimeter and clamp meter; surface thermometer; vane anemometer; spring balance to 300 N; scales to 50 kg. A machine shop makes the barrel, nozzle and mold.

**Skills.** Marking out, sawing, drilling, tapping and folding sheet; fillet welding of steel plate and tube; fitting bought parts to drawings. Mains wiring is not part of a maker's work here: it must be done or checked by a qualified electrician.

**Workspace.** A sturdy bench about 1.2 x 0.6 m that may be drilled, at about 0.9 m high, with a mains socket on an RCD and an outside wall or window for the duct; a separate fire-safe area for welding and grinding.

**Personal protective equipment.** Welding helmet, leather gloves and jacket for welding; safety glasses and hearing protection for grinding and drilling; heat-resistant gloves, long sleeves and eye protection whenever the press is hot; no loose gloves near a turning drill.

## 8. Where the numbers come from

- Model and constructability checks: `cad/src/model.py` (`python cad/src/model.py --check`, 186 checks); STEP and STL exports in `cad/step/` and `cad/stl/`.
- Pictures: `cad/src/build_plan_media.py`, using `.kit/build_views.py`; written to `docs/05-build-plan/` and `cad/drawings/MMD-DWG-101` to `MMD-DWG-115`.
- General arrangement: `cad/drawings/MMD-DWG-001.pdf`, Rev P5.
- Calculations: `docs/04-calcs/01-sizing.md` (MMD-CAL-001 v0.5) and `docs/04-calcs/sizing.py`; shot [A2], table and stacks [A5], stroke and pulls [B5], torque limit [B4a, B4b], mold screws [D1], warm-up [G4], plunger temperature [G6], mass [K1], heights [K2], cost [L1, L2].
- Bill of materials: `bom/bom.csv`.
- Decisions: `docs/decisions/0003-design-for-construction.md` (MMD-DDR-003), with MMD-DDR-001 and MMD-DDR-002; open items in `docs/06-design-decisions.md` (MMD-DEC-001).
- Requirements: `docs/03-requirements.md` (MMD-REQ-001 v0.6).

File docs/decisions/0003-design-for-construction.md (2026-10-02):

---
doc_id: MMD-DDR-003
title: MicroMold design for construction
project: MicroMold
doc_type: Design decision record
version: "0.2"
status: Draft
date: '2026-10-02'
author: Amish Chadha
license: CERN-OHL-S-2.0
revisions:
- version: "0.1"
  date: '2026-10-01'
  author: Amish Chadha
  change: Changes that make the concept physically buildable, with the reason for each; made under Amish's 2026-09-30 instruction to make the design physically buildable; open for his review
- version: "0.2"
  date: '2026-10-02'
  author: Amish Chadha
  change: Accepted by Amish on 2026-10-02 with P1 to be confirmed against the bought press before cutting, including the recommendations for A1 to A3 (plunger rest added to A1)
---

# 0003: Design for construction

- **Date:** 2026-10-01
- **Status:** accepted, with one condition. Amish, 2026-10-02: "i approve your recommendations for all 555 open decisions." This covers every change in Tables 1 and 2 and the recommendations in Table 3 (A1 to A3), which are now decided as recommended and recorded in the design decisions register (MMD-DEC-001). Condition: P1 (cutting the head from the arbor press casting and tapping four M10 holes in its back) is confirmed against the bought press before it is cut. A1 adds a plunger rest on the column, and A3 adds a torque-limiting socket on the ratchet adapter; neither is in the model yet.

## Context

On 2026-09-30 Amish asked for every repo to have a build plan that shows how each component is made and how it fits the next, with pictures, and wrote: "If you are realising that the design cannot be built as per concept - fix the design assumptions to match and be physically feasible as you draw the illustrations." The TRL 3 model of MicroMold (MMD-DDR-001 and MMD-DDR-002) showed what the press does but was a massing model: several parts overlapped, floated or had no fixing, and the screw lift could not fit where it was drawn.

The model was checked with build123d: every pair of components for shared volume, every pair that must touch for contact, the gaps that must stay open, the plunger at full stroke and the lift table at both ends of its travel. The changes below fix every problem found and keep what the press does: the same drive, ratio, stroke, bore, shot, heaters, nozzle position, mold, stack range, shield, hood and fan. Every change is in `cad/src/model.py`, which now runs 155 constructability checks, including the assembly order (`python cad/src/model.py --check`); all pass.

## Decision

*Table 1. Changes made to the model, the BOM and the calculations.*

| # | Problem in the concept | Change made | Why this way |
| --- | --- | --- | --- |
| P1 | The arbor press head overlapped the column by 30 mm and had no fixing. A 1 t arbor press is one casting, frame and head together. | The head is cut from its frame and bolted to an 8 mm head mounting plate (120 x 140 mm) welded to the column front, flush with its top, by four M10 countersunk screws into holes drilled and tapped 20 mm deep in the casting's back face. The screw heads sit flush against the column; four 22 mm holes through the column's front and back walls let a hex key reach them. The head now sits 2 mm further forward (its back face at the plate); the ram axis is unchanged. | The plate takes the head's reaction into the column corners, not its thin front wall. Countersunk screws keep the plate flat on the column, and the access holes let the head come off for repair. |
| P2 | The barrel bracket cut 3 mm into the column wall, was fixed only along the 3 mm front wall (which would bend under the 13.2 kN overload), and the flange's mica pads were not in the stack, so the flange sat directly on the steel. | The bracket is now a 20 mm shelf (110 x 150 mm) whose back edge is welded to the column face, plus an 8 mm back plate (110 x 120 mm) welded on the shelf and down both column corners. Four 15 x 15 x 3 mm mica pads sit between the shelf and the flange; the shelf top is 3 mm lower to suit. | The back plate turns the shelf's bending into a couple carried by welds on the column's side walls. The mica pads are now in the stack, as the heat-break calculation assumes. |
| P3 | The flange had no fixing, and its 80 mm diameter left no room for screws inside the funnel. | Flange 100 mm across with four M8 cap screws on an 82 mm circle into tapped holes in the shelf, with mica washers under the heads; funnel 64 mm across (was 80 mm) so a hex key reaches the screws. | The screws only hold the barrel down; the injection load goes through the pads. The narrower funnel still takes flake from a scoop. |
| P4 | The nozzle had no joint to the barrel; it just stood under it. | The nozzle screws into an M30 x 1.5 thread, 15 mm deep, in the barrel's lower end, with a 27 mm hex to tighten it; its 18 mm bore meets the 22 mm barrel bore. The tip is a 12 mm spherical radius that seats in a 12.5 mm spherical seat, 2 mm deep, in the mold top. | A threaded nozzle can be removed for cleaning. The spherical seat locates the mold on the nozzle and seals at the centre, so the test mold now sits 2 mm higher (table at 102 mm). |
| P5 | The jacket and guard floated round the barrel, and as one sleeve it could not be fitted: the barrel goes in from above through the shelf, and a sleeve cannot pass the nozzle from below. | Two half shells, front and back, that close round the barrel; each hangs on two 2 mm tabs, each on a 14 mm spacer and an M5 screw into the underside of the shelf. | Hangs the jacket from a cool part, clear of the barrel, the heaters and the nozzle, and lets it be fitted with the barrel in place. |
| P6 | The load cell, spacer and plunger were stacked with no fixings and no way to lift the plunger, and a screw through the glass-epoxy spacer would have carried heat round it. | The cell's M12 stud screws into the ram end. A plunger coupling (40 mm steel, a 22.2 mm socket 30 mm deep) hangs under a 56 mm glass-epoxy spacer on three low-head M5 screws whose heads sit in counterbores 1 mm below the spacer's top; the spacer hangs from the cell's flange on three M5 screws into blind tapped holes that stop 4 mm short of the coupling, so no metal crosses the spacer. The plunger hangs in the coupling on a 6 mm ball-lock pin through a 7 mm hole, which lets it float in line with the bore. | Keeps the thermal break the load cell needs and the floating coupling the column deflection needs. The stack is 5 mm taller; the handle top rises from 1,089 to 1,094 mm, still under the 1,100 mm limit (R9). |
| P7 | The screw lift could not be built as drawn: a 70 mm block with a crank and no mechanism, under a table whose lowest top is 60 mm above the bench. A screw jack with 100 mm of travel cannot collapse to the 50 mm between the base plate and the table. | A Tr20 x 4 screw, 150 mm long, is welded under the lift table. It runs through a handwheel nut that turns on a thrust washer on the base plate, and drops through a 25 mm hole in the base plate and the bench, up to 50 mm below the underside of a 40 mm bench. The table (now 126 mm deep) runs 2 mm in front of the column face, which stops it turning. | The only screw lift that keeps the 60 to 160 mm table range, the 120 mm stack (R7) and the nozzle height. The handwheel stays at the base, where it is reached under the closed shield front, as the concept's crank was. |
| P8 | The mold bolts ended in nuts under the lower plate, so the mold could not sit flat on the table. There was no way to line the plates up. | Four M10 x 70 cap screws into steel thread inserts in the lower plate; two 6 mm dowels; the sprue now tapers from 5 mm at the seat to 7 mm at the parting line (it was drawn the wrong way round). | The mold sits flat on the table and opens the same way each time. Inserts stop the aluminium threads wearing. |
| P9 | The shield sides started 52 mm above the bench with nothing holding them; the front had no hinge. | The sides stand on the base plate on 20 mm folded feet, two M6 screws each; the front hangs on two hinges on the left side and shuts on a latch; its bottom edge is 60 mm above the bench. | A fixed, removable guard; the handwheel is reached under the closed front. |
| P10 | The mold fan's bracket only touched the fan's lower edge. | A 3 mm plate bracket, 120 mm wide, behind the fan with a 112 mm intake hole and four M4 screws through the fan's corners; an 18 mm foot with two M6 screws into the base. The fan is 4 mm closer to the mold. | The fan is held on all four corners and can still draw air. |
| P11 | The fume hood floated beside the funnel. | An L-shaped hood arm of 30 x 5 mm flat bar: the short leg to the column's left face on two M6 rivnuts, the long leg to the hood's back on two M5 screws. | A tube wall cannot be reached from inside; rivnuts give it threads. |
| P12 | The heater wiring ran through the shield side. | Rerouted from the control box up and over the shield into the jacket. | Clears the guard and keeps the leads away from the mold zone. |
| P13 | The ratchet socket on the pinion shaft was not defined. | Ratchet adapter: the press's own lever hub with the square end of a 1/2 in drive extension welded to it, pinned to the shaft with a 6 mm roll pin. | No lathe work; the ratchet pushes onto a standard square drive. |
| P14 | Mass rose with the parts added for construction (40.7 kg against the 40 kg target). | Base plate 8 mm thick (was 12 mm); head and back plates 8 mm. | The base plate no longer carries the injection force (the force loop closes in the column), so 8 mm is enough for a bench-bolted press. The press is 39.0 kg [K1]. |
| P15 | Assembly order: the barrel's flange and band heaters cannot pass the shelf hole, so the barrel must go in from above; with the press head fitted there is too little room above the shelf. | The barrel, with its nozzle and nozzle heater, is lowered through the shelf before the press head is fitted; the band heaters clamp on afterwards; the plunger unit is assembled on the bench and screwed onto the ram as one piece. | Recorded in the build plan's step order; checked in the model. |

*Table 2. Knock-on changes.*

| Item | Change | Reason |
| --- | --- | --- |
| Mass | 39.0 kg (was 39.2 kg) with the parts added for construction, 1.0 kg under the 40 kg target [K1]. R9 stays at risk: the 8 kg head is still an assumption. | Plates and fixings added; base plate thinner. |
| Cost | BOM lines 1, 9, 10, 11, 12, 16, 17 and 18 respecified, lines 9, 12 and 16 repriced, and line 19 added (construction parts, USD 30). Value-engineering target: USD 520. Estimated cost of the constructable design: USD 544 for the press (USD 24 over the target); USD 638 with the test mold [L1, L2]. | Parts added for construction. `budget_usd` is unchanged. |
| Heat | Flange 100 mm and funnel 64 mm: the barrel zone's steel is 0.72 kg (was 0.70 kg); warm-up 12.3 min (was 12.2 min) [G1, G4]. Standing losses unchanged at 103 W. | Follows the model. |
| Height | Handle top 1,094 mm (was 1,089 mm); ram top 1,020 mm [K2]. Test mold table at 102 mm (was 100 mm) [A5]. | Coupling and nozzle seat. |
| Drawing | MMD-DWG-001 Rev P4; making sketches MMD-DWG-101 to 114 added. | Follows the model. |
| Documents | MMD-CAL-001 v0.4, MMD-REQ-001 v0.6, MMD-PRC-001 v0.6. | Follows the model. |

*Table 3. Items that change what the press does, how it is installed or its safety case: proposed, then accepted by Amish as recommended on 2026-10-02.*

| # | Question | Options | Recommendation |
| --- | --- | --- | --- |
| A1 | Loading. With the plunger raised its tip is only 8 mm above the funnel rim (the concept's stack), too little to pour flake under it. This changes how the press is used, so it is not made here. | (a) pull the ball-lock pin and lift the plunger out to load, then refit it to tamp and inject (the coupling already allows this); (b) a press with 40 mm more ram travel and a taller column (handle top about 1,134 mm, over R9's 1.1 m); (c) a side loading chute into the funnel. | (a): no new part. The plunger's top end runs at about 94 °C [G6], so it is handled in the heat-resistant gloves already required. Accepted 2026-10-02, with a simple plunger rest on the column so the hot plunger is never laid on the bench. |
| A2 | The lift screw drops through a 25 mm hole in the bench, up to 50 mm below a 40 mm bench top, so the press needs a bench it may drill. | (a) accept; (b) a 60 mm riser frame under the base plate, which raises the handle top over 1.1 m (R9). | (a). Accepted 2026-10-02. |
| A3 | Handle stop or pull limit. Recommended since TRL 3 (a 700 N pull reaches about 35 MPa and 1.35 times the press rating) but never decided, and not in the model. | (a) a stop on the ratchet arc; (b) a torque-limiting socket on the adapter; (c) rely on the written procedure and the shield. | (b): it limits force whoever pulls. Accepted 2026-10-02: the socket is set so the ram cannot exceed the press rating and is checked against the load cell at TRL 4. |

## Consequences

- Accepted by Amish on 2026-10-02 with the condition on P1. With A1 to A3 accepted: flake is loaded with the plunger lifted out and laid on a plunger rest on the column; the bench is drilled for the lift screw; a torque-limiting socket on the ratchet adapter limits the ram force to the press rating. The plunger rest and the socket are still to be added to the model, the BOM and the build plan.

- `design_state: constructable` in `project.yaml`. The build plan MMD-BLD-001 shows every component and step in pictures generated from the model (`cad/src/build_plan_media.py`).
- Requirement status (MMD-CAL-001 v0.4): none not met, 2 at risk (R2, R9), 8 met on paper, 4 met by design, 1 not verifiable at TRL 3, and R14 over the value-engineering target by USD 24.
- The appearance model `cad/src/product_model.py` and the photoreal renders (`media/render-*.png`), `media/card.png` and `media/social-preview.png` still show the concept head position, flange, funnel, screw lift, mold bolts with nuts and fan bracket. They need updating on Amish's Mac, where Blender is.
- The arbor press is chosen at TRL 4: its ram length and travel, whether its head can be cut from the frame and drilled, and its mass must be checked then (design decisions register, items to confirm).

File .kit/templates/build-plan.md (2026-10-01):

---
doc_id: PRJ-BLD-001
title: Project prototype build plan
project: Project name
doc_type: Build plan
version: "0.1"
status: Draft
date: YYYY-MM-DD
author: Amish Chadha
license: CERN-OHL-S-2.0
revisions:
  - version: "0.1"
    date: YYYY-MM-DD
    author: Amish Chadha
    change: First build plan; design made constructable
---

# Project prototype build plan

**Plan, not yet built.** How to build the first proof-of-concept prototype, component by component. Building and testing to it is TRL 4 work. Decisions still to be made are kept in the design decisions register (`docs/06-design-decisions.md`), not here.

## 1. What you are building

Every component, pulled apart and numbered in build order

One short paragraph: what the prototype is, how many components, which are made and which are bought, and the main ways they are made.

## 2. What changed to make it buildable

| Component | The concept had | The buildable design has | Why |
| --- | --- | --- | --- |

## 3. Making the components

### 3.1 Component name

Making sketch

**What it is and what it is made from.**

**How to make it.**

1. Mark out ...
2. Cut ...

**How it fits the parts next to it.**

Close-up of the joint

**Check before moving on.**

## 4. Putting it together

### Step 1: ...

Step 1

## 5. First checks

| Check | Requirement | How | Pass when |
| --- | --- | --- | --- |

## 6. Safety stops

## 7. Tools, skills and workspace

## 8. Where the numbers come from

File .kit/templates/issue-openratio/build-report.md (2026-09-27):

---
name: Build report
about: Tell us what happened when you built, printed or tested part of this design
title: "Build report: "
labels: build-report
---

This is a research and educational prototype, not a medical device. It is a TRL 3 concept and is not released for fabrication. If you build any part of it, you do so at your own risk. Reports help everyone.

**What you built** (part, sub-assembly or test)

**Materials, tools and settings**

**What worked**

**What did not work, with photos or measurements if you have them**

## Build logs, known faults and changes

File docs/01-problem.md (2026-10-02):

---
doc_id: MMD-PRB-001
title: MicroMold problem statement
project: MicroMold
doc_type: Problem statement
version: "0.6"
status: Draft
date: '2026-10-02'
author: Amish Chadha
license: CERN-OHL-S-2.0
revisions:
- version: "0.1"
  date: '2026-09-25'
  author: Amish Chadha
  change: Initial scaffold
- version: "0.2"
  date: '2026-09-25'
  author: Amish Chadha
  change: Populate to TRL 2 (users, context, constraints, out of scope, prior work with sources)
- version: "0.3"
  date: '2026-09-25'
  author: Amish Chadha
  change: TRL 3 update (budget covers the press with molds as tooling, fume extraction, feedstock grade, co-design partner type; MMD-DDR-001)
- version: "0.4"
  date: '2026-09-25'
  author: Amish Chadha
  change: Recommendations accepted by Amish (DDR-002)
- version: "0.5"
  date: '2026-09-26'
  author: Amish Chadha
  change: Budget approved by Amish ($520)
- version: "0.6"
  date: '2026-10-02'
  author: Amish Chadha
  change: First candidate co-design partner, as decided by Amish on 2026-10-02
---

# MicroMold problem statement

Small recycling groups can collect, sort, wash and shred plastic, but they struggle to turn the flake into products that people will pay for. Selling baled or shredded plastic returns little, and injection molding, the process that makes most small plastic parts, normally needs machines and steel tooling far beyond a community budget. MicroMold aims to close that gap with a bench-top injection press that a local workshop can build for a few hundred dollars and that runs aluminum molds a small machine shop can cut. The target is $520 for the press, with molds counted as tooling (MMD-DDR-002, approved by Amish on 2026-09-26); the TRL 3 estimate is $507 (MMD-CAL-001).

## The problem in numbers

- Only about 9 % of plastic waste was recycled worldwide in 2019, after losses in recycling; the rest was landfilled, incinerated or leaked into the environment ([OECD, *Global Plastics Outlook*, 2022](https://www.oecd.org/en/publications/global-plastics-outlook_de747aef-en.html)).
- Municipal solid waste reached 2.56 billion tonnes in 2022 and is heading for 3.86 billion tonnes by 2050. Collection covers only 31 % of waste in sub-Saharan Africa and 67 % in South Asia, and most uncollected waste is dumped in the open ([World Bank, *What a Waste 3.0*](https://www.worldbank.org/en/publication/what-a-waste)).
- Even in a high-income country the rate is low: the United States generated 35.7 million tons of plastics in 2018 and recycled 8.7 % ([US EPA](https://www.epa.gov/facts-and-figures-about-materials-waste-and-recycling/plastics-material-specific-data)).
- Exporting scrap is getting harder. Since 1 January 2021 the Basel Convention plastic waste amendments require prior informed consent for most mixed or contaminated plastic waste shipments ([Basel Convention](https://www.basel.int/implementation/plasticwaste/amendments/overview/tabid/8426/default.aspx)), so value has to be added closer to where waste is collected.

## Users and context

Primary users (to be confirmed through co-design):

- **Community recycling groups and waste picker cooperatives** that already sort and shred HDPE and PP and want a product line (hooks, knobs, clips, spare parts, tiles) rather than selling flake by weight.
- **Precious Plastic style workspaces and makerspaces** that want a smaller, cheaper and more precise injection press than the community's lever machine, for short runs of small parts.
- **Schools, technical and vocational colleges and design courses** teaching polymer processing, mold design and the circular economy.
- **Repair shops and small workshops** that need short runs of simple replacement parts (knobs, spacers, bushings, clips) that are no longer sold.

Typical context: a covered workshop or container with single-phase mains (230 V or 120 V), a bench, hand tools, a drill press and access to a local machine shop with a lathe and a mill. Feedstock is washed, dried and shredded flake of one resin type from injection-molded items such as caps, crates and buckets (MMD-REQ-001 R1), because bottle-grade HDPE flows too stiffly for a hand press (MMD-CAL-001, E6), sorted by the group itself or with tools such as WasteWise Scan. MicroMold sits at the end of the plastics line described in the ReflowEconomy playbook.

## Constraints

- Garage-buildable prototype for $520 USD in parts for the press, with molds counted as tooling (`project.yaml`; MMD-DDR-001 D8, MMD-DDR-002); see MMD-REQ-001 R14 for the current estimate.
- Single-phase mains, 1 kW or less, so it runs from an ordinary socket or a small generator.
- Only the barrel and the molds may need machining; everything else built with hand tools, a drill press and optional welding.
- Molds in aluminum, cut on a manual mill or small CNC, so a new product costs tens to low hundreds of dollars in tooling rather than thousands.
- Safe processing only: HDPE, PP, LDPE and PS. PVC must never be heated, because it releases hydrogen chloride and other harmful products ([Precious Plastic Academy, "Plastic basics"](https://onearmy.github.io/academy/plastic/basics)).
- Hand-operated injection, so no hydraulics or motors are needed; the only motor is the fume extraction fan.
- Fumes must be captured at the press (a side hood and duct fan) or the press run outdoors (MMD-DDR-001 D9).

## Out of scope

- Production molding at industrial pressures (50 MPa and above) or cycle times of seconds.
- PET, PVC, engineering plastics (PA, PC, ABS blends) and mixed or unknown plastics.
- Shredding, washing and drying equipment (covered by other open machines and the ReflowEconomy playbook).
- Food-contact, medical or safety-critical parts. Recycled feedstock of unknown history cannot support those claims.

## Prior work

- **Precious Plastic injection machine.** The open reference design: a floor-standing lever press, 830 x 700 x 1,300 mm and 23 kg, with a 150 cm³ barrel, a 3:1 lever giving about 45 bar (4.5 MPa), 10 to 30 injections per hour and about €300 in new materials in the Netherlands. It runs HDPE, LDPE, PP and PS ([Precious Plastic Academy, "Injection"](https://onearmy.github.io/academy/build/injection)). MicroMold trades shot size for about twice the pressure and a bench footprint.
- **Commercial bench-top injection presses** for hobby and lab use exist, with lever or pneumatic drives. They are closed designs and usually sized for virgin pellets rather than irregular flake. No figures are cited here until sources are checked at TRL 3.
- **Processing data.** Published melt temperature ranges are 190 to 230 °C for HDPE, 200 to 240 °C for PP, 220 to 245 °C for LDPE and 180 to 260 °C for PS ([RJC Mold, "Plastic Melting Point Chart"](https://rjcmold.com/guides/plastic-melting-point-chart)).
- **Portfolio links.** WasteWise Scan (resin identification), WasteWise-ml (material classification) and ReflowEconomy (micro-factory playbook) supply sorted feedstock and the operating context.

> **Safety:** The problem involves mains-powered heaters, surfaces and melt at 180 to 260 °C, pressurized molten plastic and fumes. See the safety section of MMD-PRC-001.

## User research and co-design

This design is for communities the author is not part of, so requirements come from the people who will use it.

- [ ] Identify a local partner organization (Helpful Engineering network, NGO or university). Decided by Amish, 2026-09-25: the first partner is to be a group that already shreds HDPE or PP (MMD-DDR-001 D10); Decided by Amish, 2026-10-02: a Precious Plastic workspace near Irving, Texas, is the first candidate to approach (MMD-DEC-001). Recruiting is on hold while TRL 4 is on hold.
- [ ] Run co-design sessions with intended users; record who, where and what was learned
- [ ] Validate load, distance, terrain and cost assumptions in the field
- [ ] Revise requirements (REQ) from findings before freezing the design

Questions to take to users: which parts would sell locally and at what price; the part size and shot size they need; how many parts per day make the press worth running; who in the group would machine molds; and what power supply is reliable.

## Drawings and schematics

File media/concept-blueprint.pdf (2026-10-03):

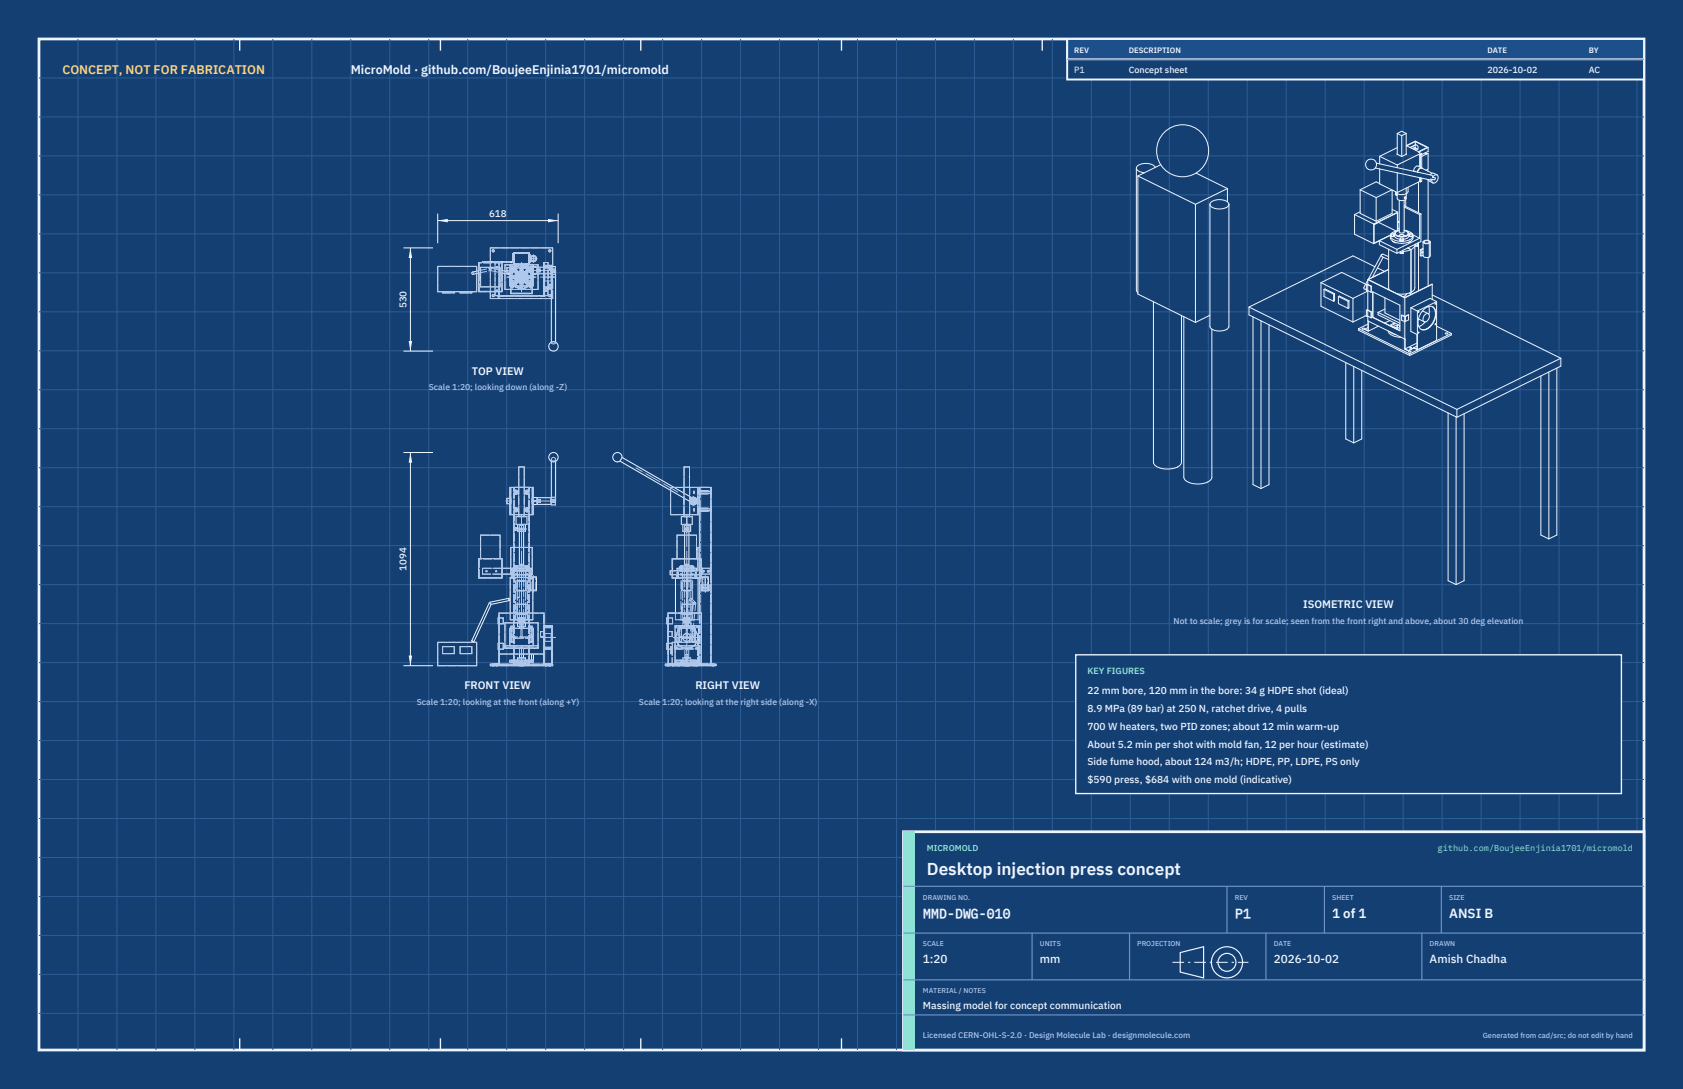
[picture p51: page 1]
CONCEPT, NOT FOR FABRICATION; MicroMold · github.com/BoujeeEnjinia1701/micromold; FRONT VIEW; TOP VIEW; RIGHT VIEW; ISOMETRIC VIEW; REV; DESCRIPTION; DATE; Concept sheet; MICROMOLD; github.com/BoujeeEnjinia1701/micromold; DRAWING NO. MMD-DWG-010; REV P1; SHEET 1 of 1; SIZE ANSI B; SCALE 1:20; UNITS mm; PROJECTION; DRAWN Amish Chadha; Licensed CERN-OHL-S-2.0 · Design Molecule Lab · designmolecule.com; Generated from cad/src; do not edit by hand

Scale 1:20; looking down (along -Z)

Not to scale; grey is for scale; seen from the front right and above, about 30 deg elevation

KEY FIGURES
22 mm bore, 120 mm in the bore: 34 g HDPE shot (ideal)
8.9 MPa (89 bar) at 250 N, ratchet drive, 4 pulls
700 W heaters, two PID zones; about 12 min warm-up
About 5.2 min per shot with mold fan, 12 per hour (estimate)
Side fume hood, about 124 m3/h; HDPE, PP, LDPE, PS only
$590 press, $684 with one mold (indicative)

Scale 1:20; looking at the front (along +Y)

Scale 1:20; looking at the right side (along -X)

Desktop injection press concept

MATERIAL / NOTES
Massing model for concept communication

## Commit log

2026-09-25 Initial scaffold: standard open hardware layout, CERN-OHL-S v2 + MIT licenses
    Claude-Session: https://claude.ai/code/session_01XuhhSU4W6fYhgCfURbrkut
    [bom.csv]
2026-09-25 Populate to TRL 2: problem, requirements, precis, concept media, BOM and README use cases
    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
    [bom.csv]
2026-09-26 Advance to TRL 3: DDR-001, CAL-001 sizing, parametric model with STEP/STL, GA drawing, priced BOM; TRL 4 on hold
    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
    [barrel-set.step, barrel-set.stl, bom.csv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]
2026-09-26 Accept all recommendations (DDR-002), switch footer to designmolecule.com, add README write-up with new inspiration point
    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
    [barrel-set.step, bom.csv, micromold-assembly.step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]
2026-09-27 Product appearance model and photoreal renders
    Adds cad/src/product_model.py (appearance model for renders only, all main
    dimensions from model.py) and Blender renders in media/render-*.png,
    captioned with the project, repository and viewing direction. README leads
    with the product render; trl stays 3.
    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
2026-10-01 Image quality pass: legible exploded views, flow diagrams and drawing sheets
    Kit 1.6.1 image layout: the parts list sits in its own column, number bubbles sit on visible parts and never overlap, small parts get a leader, pictures are cropped to the subject, flow labels keep numbers with their units, and sheet captions and the revision table no longer overprint. Concept images, blueprint and general arrangement sheet regenerated; repo-specific labels moved clear of other text and lines.
2026-10-01 Kit 1.7.0: constructable design, illustrated build plan and design decisions register
    The design is now constructable: every part can be made and fits its neighbours, with each change recorded in a Design for construction decision record (made under Amish's 2026-09-30 instruction; ope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
    FlexHand also credits Dr. Geeti Chadha as a contribut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
    [barrel-set.step, barrel-set.stl, bom.csv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]
2026-10-02 Record Amish's approval of the open-decision recommendations
    Amish approved the recommendation on every open decision in the design decisions register ("i approve your recommendations for all 555 open decisions.", 2026-10-02). Each decision is moved to Decisio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
2026-10-03 Carry approved follow-ups into the design and redo photoreal renders
    Amish approved the follow-up actions from the open-decision sign-off ("APPROVED CHANGES, COMPLETE THESE", 2026-10-02), the design-for-construction change tables in ten repos, the last wave's open dec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
    [barrel-set.step, bom.csv, micromold-assembly.step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]
2026-10-03 Record Amish's 2026-10-03 decisions; FlatTrike fork and PotPress guard fixes
    Amish, 2026-10-03: "PalletPilot - i accept it"; "FlatTrike - i accept your design recommendation, proceed and execute the solution for fork direction or caster"; "PotPress - move forward with the four guard fixes. I accept the cost."; "GravitySort - i accept your recommendation"; "TIght Margins - i accept the margins"; "Cost over target - i accept all the cost variations and overruns". FlatTrike knuckle forks turned to trail (35 mm trail); PotPress finer mesh, small-hole plates, top beam and crank bracket covers, ISO 13857 desk check now met on paper. Registers, requirements, drawings, pictures, renders and PDFs upd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

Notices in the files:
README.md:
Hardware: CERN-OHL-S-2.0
